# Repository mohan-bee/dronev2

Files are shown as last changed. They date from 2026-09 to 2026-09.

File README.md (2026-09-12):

# Drone V2

A compact, two-layer PCB microdrone with an interactive assembly viewer.

[Open the live 3D assembly studio](https://dronev2-cad.vercel.app)

- `pcb/` — tscircuit source, JLCPCB imports, mechanical dimensions, netlist tests and placement drawings.
- `cad/` — Three.js assembly viewer, generated PCB data and Vercel configuration.
- [ISSUES.md](ISSUES.md) — tooling blockers, mechanical assumptions and work required before routing/manufacture.

The two-layer specification supersedes the earlier four-layer proposal. Routing is deliberately disabled. No fabrication or flight release is implied.

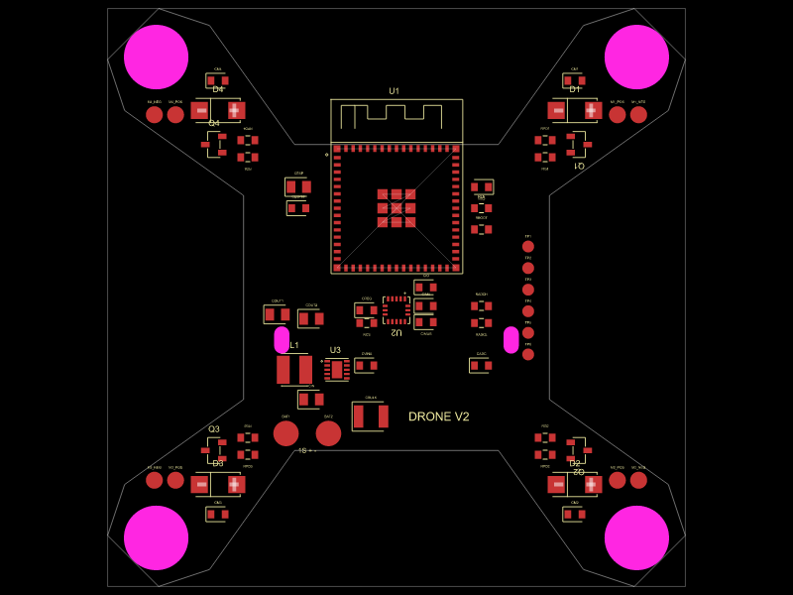
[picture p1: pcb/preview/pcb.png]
PCB placement


See [PCB instructions](pcb/README.md) for setup, validation, sourcing and pin mapping.

See [CAD instructions](cad/README.md) for the viewer, PCB sync, browser tests and deployment. The CAD PR is stacked on the PCB placement PR; merge the PCB first.

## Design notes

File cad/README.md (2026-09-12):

# Assembly studio

[Live viewer](https://dronev2-cad.vercel.app)

Interactive Three.js CAD-style viewer for the Drone V2 PCB. Orbit, inspect components, choose camera views, toggle parts, explode the assembly and export visible geometry as GLB. It does not edit PCB placement or control a flying drone.

```sh
cd cad
bun install --frozen-lockfile
bun run dev
bun run build
bunx playwright test
```

For tests, install Playwright Chromium with `bunx playwright install chromium` when a local Chrome installation is unavailable. Tests start the dev server automatically. `TEST_URL` can target an existing deployment.

## Updating the PCB

Build and validate `../pcb` first, then run `bun run sync-pcb`. The script refuses circuit JSON containing error records. It copies the source outline, holes, pads, component placements, drawing exports and vendor models into `public/pcb/`; `provenance.json` identifies the circuit JSON by SHA-256. Committed generated assets keep Vercel builds independent of the PCB toolchain.

## Model fidelity

PCB outline/holes/pads and electronic placements are compiled tscircuit data. Main components use JLCPCB-imported OBJ geometry, with approximate display materials because the importer did not provide material libraries. Passive parts use generic package envelopes. The four motors, propellers, battery, collars, guards, canopy, insulating pad and zip tie are provisional dimensional concepts. The canopy starts hidden so electronics can be inspected.

The page labels these limits. Export preserves visible parts and explosion state, converts millimetres to glTF metres and excludes the scene floor/grid and selection outline. Printed parts are not print-ready mechanical designs. No flight, mass or clearance validation is claimed.

## Deploy

Vercel project: `dronev2-cad`, GitHub root directory `cad`. Production is deployed from the repository root using its linked project, or through the Vercel GitHub integration after merge. No runtime environment variables are required. `.vercel/` and `.env*` are ignored.

## Verified result

Production smoke tests passed on the live URL: desktop model loading, component inspection, views, exploded state, selection/visibility consistency, GLB download, mobile layout and parts drawer. The rendered PCB provenance hash matches the compiled source.

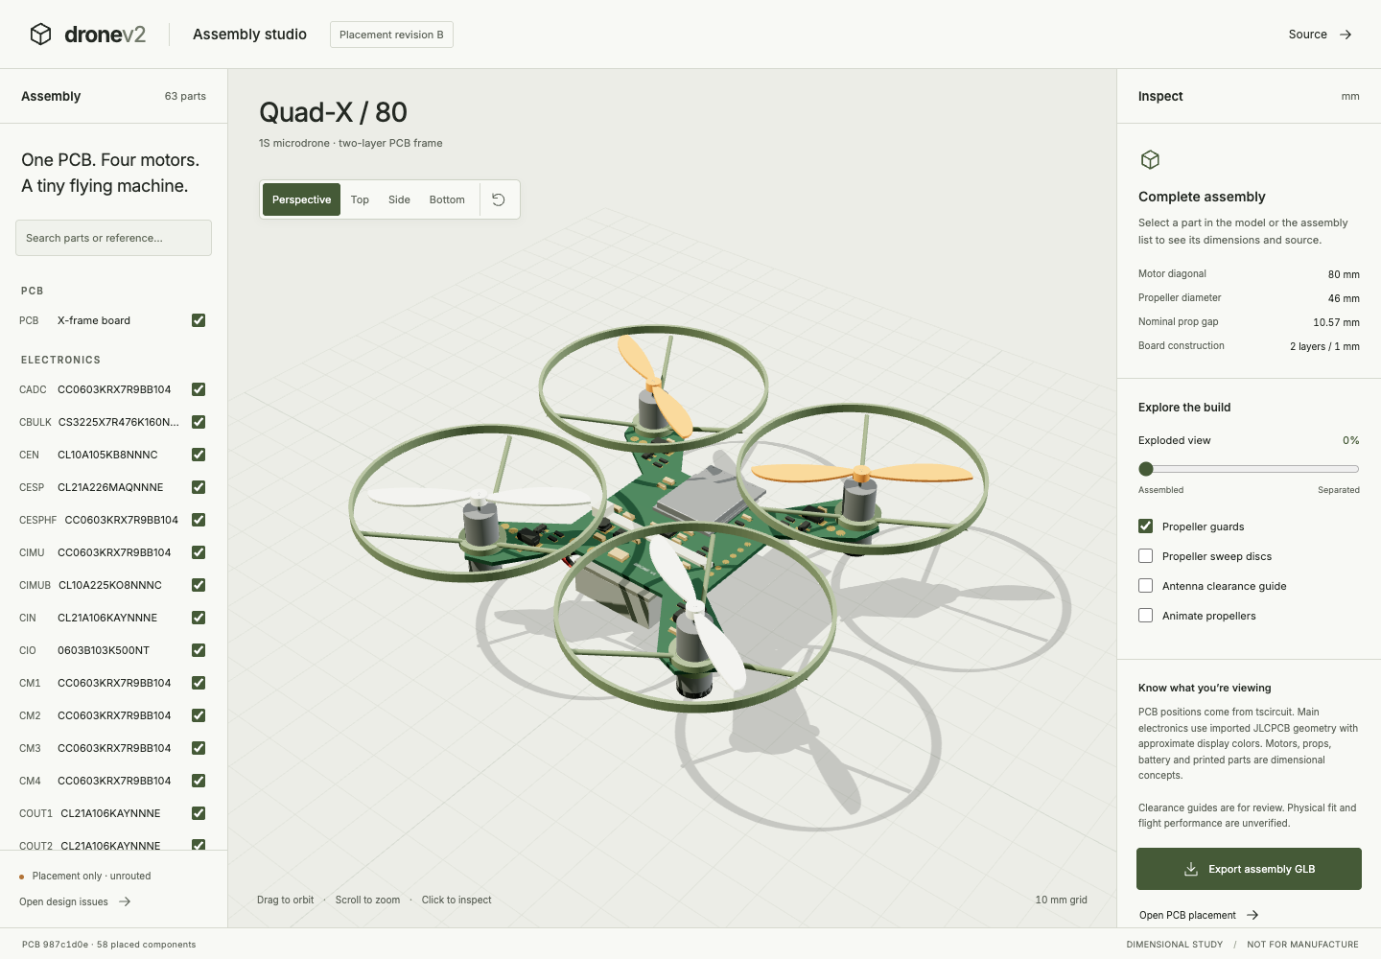
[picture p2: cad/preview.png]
Assembly studio


Revision B replaces the printed battery saddle with a 1 mm insulating pad and a 2.5 mm zip tie through two actual rounded PCB slots. The top run has a checked component-free lane. Motor collars are labeled as unselected mount placeholders; rubber supplier dimensions remain unresolved in ISSUES.md.

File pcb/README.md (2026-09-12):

# Compact PCB placement

A 68 × 68 mm X-shaped PCB frame with 58 top-side placed components/pads, 80 mm opposite-motor spacing, four 7.6 mm collar openings, and an ESP32-S3 antenna overhanging the nose. The central body is 36 mm wide; nominal neighboring 46 mm prop discs have 10.57 mm clearance. PCB thickness is 1.0 mm, two layers, FR-4. The fabrication target is 1 oz copper and ENIG, to be specified at order time.

## Run

Requires Bun. Dependencies are locked.

```sh
cd pcb
bun install --frozen-lockfile
bun run check
bun run build -- --routing-disabled --pcb-png --svgs
bun test
bun run typecheck
bun run dev
```

`index.circuit.tsx` is the source. `geometry.json` owns the outline and motor locations; `keepouts.json` records unenforced copper and mechanical requirements. The CAD viewer consumes the compiled output, not a second hand-placed board.

## Placement decisions

- U1 at (0, 10.5): every solder pad stays over the PCB; only the antenna body overhangs. Keep antenna space clear in the final assembled product.
- U2 at (0, -1.5), rotated 180°: near the center with local VDD/VDDIO/REGOUT capacitors. Configure firmware sensor axes from the actual package orientation.
- U3 and L1 form a compact cluster at the rear-left battery input. Input/output bypassing stays local; route these switching loops manually first. PS/SYNC is tied to VBAT for forced PWM; FB returns to V3V3.
- One Q/D/RG/RPD/CM group on each arm. Motor solder pads and flyback diodes stay close to the drain; GPIO gate traces travel inward. CM footprints are across motor terminals, not VBAT–GND. Also fit suppression at actual motor terminals if noise tests require it.
- Programming pads along the right edge. TP1 GND, TP2 **3V3_TEST**, TP3 controller TX, TP4 controller RX, TP5 EN, TP6 BOOT. TP2 is a measurement point, not an invitation to parallel an external supply with the regulator. Use a 3.3 V logic programmer.
- BAT1 is positive, BAT2 negative. Use a polarity-verified battery pigtail; no unverified connector footprint is assumed.
- Holes H5/H6 reserve potential printed-part attachment locations; no hardware should press beneath the IMU.

## Pin assignment

| Function | GPIO | Module pad |
|---|---:|---:|
| SPI clock | 12 | 16 |
| SPI MOSI | 11 | 15 |
| SPI MISO | 13 | 17 |
| IMU CS | 8 | 12 |
| IMU interrupt | 14 | 18 |
| Motor M1 | 39 | 35 |
| Motor M2 | 40 | 36 |
| Motor M3 | 41 | 37 |
| Motor M4 | 42 | 38 |
| Battery ADC | 1 | 5 |
| UART TX / RX | 43 / 44 | 39 / 40 |
| BOOT / EN | 0 / — | 4 / 45 |

M1 is front-right, M2 rear-right, M3 rear-left, M4 front-left; +Y is forward. CW/CCW in CAD is a proposed alternating arrangement, not a verified ESP-FC mixer order. Firmware, rotation and sensor-axis configuration remain a separate task.

## JLCPCB sourcing

Exact EasyEDA footprints plus local OBJ/STEP models were imported using:

```sh
bunx tsci import C2913206 --jlcpcb --download --use-exact-footprint
```

Repeated for C97633, C15516, C20917, C8678 and C2041714. Reimporting may overwrite generated files; the board overrides the unreadable imported AO3400A schematic symbol with a pin box and retains its footprint/model. Importer-generated pin aliases such as `pin7` on TPS63031 are wired by verified numeric pad mapping.

See [bom.csv](bom.csv) for the selected parts. Generic passive footprints carry explicit JLCPCB candidate codes; they are not all individually imported vendor footprints. Stock and pricing are not reserved. Capacitor effective capacitance and inductor saturation require qualification under actual operating conditions.

## Validation scope

See [reports/validation.md](reports/validation.md). Checks cover connectivity and placement; there are no routed copper traces. The independent netlist assertions cover regulator pin mapping, sensor reserved pins, SPI mapping and all four low-side motor circuits. Nothing here validates thrust, thermal margins, RF performance or flight firmware.

## Manufacturer references

- [ESP32-S3-MINI-1 datasheet](https://documentation.espressif.com/esp32-s3-mini-1_mini-1u_datasheet_en.html)
- [ICM-20602 datasheet](https://invensense.tdk.com/wp-content/uploads/2020/11/DS-000176-ICM-20602-v1.1.pdf)
- [TPS63030/TPS63031 datasheet](https://www.ti.com/lit/ds/symlink/tps63030.pdf)
- [AO3400A datasheet](https://www.aosmd.com/sites/default/files/res/datasheets/AO3400A.pdf)
- [Selected Bourns inductor listing](https://jlcpcb.com/partdetail/BOURNS-SRN30151R5Y/C2041714)
- [ESP-FC firmware](https://github.com/rtlopez/esp-fc)

The user's two supplied specifications are preserved under `docs/`.

Battery retention uses one 2.5 mm zip tie through H5/H6 (1.8 × 3.2 mm rounded slots) at x=±13.5, y=-5 mm, with a thin insulating pad. The top strap lane is kept clear of components. No printed battery saddle is required. Fit and slip testing remain necessary.

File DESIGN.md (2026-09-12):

# Assembly studio

Mode: Operate. A light model-making bench: warm off-white canvas, ink typography, olive active controls, orange selection. The assembly owns most of the viewport. Parts hierarchy at left; dimensional inspection at right. Dense data uses tabular numerals. Controls stay ordinary buttons, checkboxes and sliders.

The user delegated the stack and visual direction and requested a direct build. Considered systems: engineering drawing, parts catalogue, camera workbench, flight checklist, model-making bench, service manual, fabrication traveler. Selected model-making bench. Map legend contributes explicit symbols; oscilloscope contributes measured scale; folding sheet contributes reversible explosion. Game sprites, typographic storms and scroller queues undermine dimensional clarity and are declined.

Tokens: canvas #ecede7; paper #f8f9f5; ink #242923; secondary #60665c; rule #d6d9cf; active #455a37; highlight #c66935. Inter Variable, 13px body baseline; 28px scene heading (weight 450), 15px header title (weight 500), 23px brand. Controls generally use 11px, metadata 9–10px. Spacing is contextual rather than a strict 4px grid. Corners are 3px on rows/view buttons, 4px on search/export, and 5px on the toolbar. Real model geometry with ground shadow, no decorative cards. At 820px and below, mobile puts the canvas (64dvh, minimum 430px) before a two-column inspector in document flow. Only the assembly list becomes a 260px overlay, toggled by Parts.

## Layout and interaction details

Desktop has a 72px header, a 238px / flexible canvas / 276px workspace, and a 33px footer. The workspace has a 620px minimum height; side panels scroll independently. At 1600px and above side columns become 265px and 300px. At 1100px and below they become 205px and 240px, panel padding falls from 22px to 17px, and revision/grid captions hide. Mobile uses a 60px header and a 24px scene heading.

Selection uses a pale olive list row (#e0e7d7, text #304424) and an orange bounding box in the model. Focus-visible outlines are olive, 2px with 4px offset. The toolbar has a faint shadow (0 3px 8px #24292308); the mobile parts overlay uses 8px 10px 30px #24292325. Export hover darkens to #34462a; pending buttons have half opacity and a wait cursor.

Camera presets switch directly; reset restores perspective and collapses explosion. Slider changes directly separate model groups and refit the camera. Orbit uses damping. Propeller animation is opt-in and disabled when reduced motion is requested at load. Selection, camera changes and export status are announced in a polite live region. Export contains the visible assembly.

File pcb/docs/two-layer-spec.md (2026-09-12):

**Yes—we can build this as a two-layer PCB, with the PCB itself forming the drone’s body and all components assembled on top.** Espressif explicitly allows two-layer ESP32-S3 designs, provided the bottom layer remains mostly an uninterrupted ground reference rather than becoming another busy signal-routing layer. ([docs.espressif.com][1])

For your drone, I would keep the selected **ESP32-S3-MINI-1-N8, ICM-20602, TPS63031, and four AO3400A motor switches**.

**Two layers do not inherently create control lag.** The concern is electrical noise and voltage dips from the motors—not “buffering” caused by the layer count. Motor noise can disturb sensors and even reset a controller, so the power layout deserves particular attention. ([Pololu][2])

# 1. PCB specification I would start with

These are **proposed design targets**, not a flight-tested mechanical design.

| Item | Proposed specification |
| --- | --- |
| Board construction  | **Two-layer FR-4** |
| Board thickness | **1.0 mm initially**, then verify stiffness |
| Copper | **1 oz on both sides** |
| Surface finish | **ENIG preferred** |
| Component assembly  | **Top side only** |
| Shape | **X-shaped PCB that also serves as the frame** |
| Motor spacing | **80 mm between opposite motor centres** |
| Propellers | **46 mm** |
| Motor mounting | Printed collars attached to the PCB arms |
| Battery mounting | Under the centre, with electrical insulation |
| Complete drone mass | Continue targeting **30–35 g**, subject to measured thrust |

JLCPCB lists two-layer FR-4, 1.0 mm thickness, 1 oz copper, and ENIG among its manufacturing options. These choices do not establish the final assembly price or component inventory. ([JLCPCB][3])

At an 80 mm motor diagonal, adjacent motor centres are approximately **56.6 mm apart**. With 46 mm propellers, the nominal gap between adjacent propeller discs is approximately **10.6 mm**.

**Do not make the arms extremely thin just to reduce weight.** My preference is to begin with fairly broad, rounded arm roots, then remove material only after checking mass and flex.

# 2. Decide what belongs on each copper layer

| Top copper | Bottom copper |
| --- | --- |
| All component footprints | Mostly connected GND copper |
| Battery-positive distribution | Motor-current return paths through broad ground areas |
| Short motor-switching connections | Ground connections for controller and power circuitry |
| Regulated 3.3 V distribution | Only a few short signal crossings where necessary |
| SPI, motor-control, and programming signals | Required antenna and sensor footprint keepouts |

The manufacturer-backed principle is **top-side components and signals, with minimal bottom routing**. ([docs.espressif.com][1])

For this design, I would use **one common GND net**, while arranging the components and power branches so motor current does not have to squeeze through the controller/sensor area. Do not create separate, floating “motor ground” and “sensor ground” islands.

There are two important exceptions to a broad ground pour: the **antenna clearance area** and the **local keepout under the IMU package**. The latter follows TDK’s sensor-layout guidance; it is a small footprint-level clearance, not a long slot dividing the whole board. ([Mouser Electronics][4])

# 3. Place components before routing anything

### ESP module: front edge, antenna facing outward

Position the module so its antenna end extends beyond the supporting PCB edge where practical. Keep the battery, motor wires, and printed attachments away from that area. Espressif recommends antenna clearance in the finished product and testing the final assembly’s communication performance. ([Espressif Systems][1])

**Do not remove ground beneath the entire module.** Apply the antenna keepout specifically, while following the recommended land pattern for the rest of the module.

### IMU: near the centre, in a mechanically quiet location

I would put the ICM-20602 near the centre of the drone, but allow a slight offset to avoid a mounting point, heavily flexing area, or hot component.

Keep it away from the regulator’s inductor, motor-current paths, mounting screws, and pressure from the battery holder. TDK specifically warns about mechanical stress, heat sources, vibration, and connectors or test fixtures directly beneath an IMU. ([Mouser Electronics][4])

### Regulator: beside the battery input

Place the TPS63031, its inductor, and its input/output capacitors together as a compact group. Do not scatter them around spare spaces on the PCB. TI’s layout guidance calls for short, wide power connections and closely placed capacitors and inductor.

### Motor circuits: one group near each motor connection

My proposed arrangement is one MOSFET, diode, gate resistor, and gate pull-down near each motor’s solder pads. This keeps the switched motor-negative connection short, while the much lower-current gate-control trace travels along the arm.

### Programming pads: accessible along a side

Keep programming access away from the IMU and outside the battery-holder contact area. You should be able to connect a programmer without removing motors or pressing on the sensor.

# 4. Draw the schematic in five blocks

## A. Battery input and 3.3 V supply

Use this power arrangement:

```text
1S LiPo positive
    |
    +---- Motor 1 positive
    +---- Motor 2 positive
    +---- Motor 3 positive
    +---- Motor 4 positive
    |
    +---- TPS63031 ---- regulated 3.3 V
                           |
                           +---- ESP32-S3 module
                           +---- ICM-20602

Battery negative -------- common GND
```

**The motors connect to the battery rail—not the regulator’s 3.3 V output.**

For the TPS63031, start from TI’s **fixed-3.3 V application circuit**, not the adjustable TPS63030 circuit:

| Item | Reference-circuit value / connection |
| --- | --- |
| Inductor | **1.5 µH**, appropriately rated for peak current |
| Input capacitor | **10 µF** |
| Output capacitors | **2 × 10 µF** |
| VINA bypass capacitor | **100 nF** |
| FB pin | Connect to the 3.3 V output |
| EN | Defined high for normal always-on operation |
| PS/SYNC | High disables power-save mode; low enables it |

The capacitor values must remain adequate after voltage derating. Follow TI’s local power-ground/control-ground arrangement and exposed-pad requirements.

For the first prototype, I would provision **PS/SYNC high during flight** and reserve space for additional battery-rail bulk capacitance.

**Power-budget caution:** TPS63031 is specified for up to 500 mA in boost operation under its stated conditions; its “1-A switches” description is not a 1 A output guarantee. Espressif recommends a supply capable of at least 500 mA. This makes low-battery, radio-active testing essential before accepting this regulator for the finished drone. ([Texas Instruments][5])

## B. ESP32-S3 minimum circuit

For the module—not a bare ESP32-S3 chip—include:

| Connection | Implementation |
| --- | --- |
| 3V3 | Regulated 3.3 V |
| Local supply capacitors | **22 µF + 100 nF**, as shown in the module reference |
| EN | **10 kΩ pull-up to 3.3 V + 1 µF to GND** as the initial reset network |
| BOOT / GPIO0 | Accessible connection to GND for entering download mode |
| UART | TX, RX, and GND programming pads |
| Ground pads | Connect according to the module land pattern |

The module reference provides the supply and reset circuitry; the EN timing should still be checked with the actual regulator.

I would add an external **10 kΩ GPIO0 pull-up** and expose:

```text
GND   3V3_TEST   TX   RX   EN   BOOT
```

Use a **3.3 V-logic programmer**. Label `3V3_TEST` clearly: it should not encourage connecting an external supply in parallel with the onboard regulator.

## C. ICM-20602 circuit

Power **VDD and VDDIO from the regulated sensor supply**, not directly from the LiPo.

Use the manufacturer’s actual capacitor arrangement:

| ICM-20602 connection | Required external connection |
| --- | --- |
| VDD, pin 16 | **100 nF + 2.2 µF** to GND |
| VDDIO, pin 1 | **10 nF** to GND |
| REGOUT, pin 14 | **100 nF** to GND |
| FSYNC, pin 8 | GND when unused |
| Reserved pin 7 | Leave electrically unconnected |
| Reserved pins 9, 10, 11, 12, 15 | GND |
| GND, pin 13 | GND |

**REGOUT is not a general-purpose supply output.** Also, do not treat every reserved pin identically.

Use SPI: clock to `SCL/SPC`, MOSI to `SDA/SDI`, MISO from `SA0/SDO`, and a GPIO-controlled `CS`. I would add a **10 kΩ CS pull-up** and reserve an interrupt connection. Do not copy the datasheet’s I²C example with CS permanently tied high.

Place these capacitors immediately beside their corresponding pins. Keep SPI routes short, reasonably similar in length, and away from switching-power traces; respect the under-package copper/via keepout. ([Mouser Electronics][4])

## D. Four brushed-motor driver circuits

Repeat this circuit four times:

```text
VBAT -------------------- Motor positive
                              |
                            MOTOR
                              |
Motor negative ---------------+---- AO3400A DRAIN

AO3400A SOURCE -------------------- GND

ESP motor GPIO ---- 100 Ω --------- AO3400A GATE
                                      |
                                    100 kΩ
                                      |
                                  SOURCE / GND
```

Place the **SS34 diode across the motor connection**:

**Diode cathode → VBAT / motor positive.**
**Diode anode → motor negative / MOSFET drain.**

This low-side-switch and flyback-diode topology is also used in Espressif’s drone reference, although its exact transistor, diode, and resistor choices differ.

The 100 Ω and 100 kΩ values above are my proposed starting values. Put both close to the MOSFET. Verify the actual AO3400A footprint’s gate/source/drain mapping against its datasheet, rather than trusting an imported symbol.

For motor-noise suppression, provision a small ceramic capacitor across each motor’s terminals. Pololu recommends terminal capacitors and short, twisted motor leads; its general starting recommendation is 100 nF. Validate the chosen capacitor with your motor PWM and switching waveform. ([Pololu][2])

**A capacitor between VBAT and GND is not the same connection as a capacitor across the motor.**

## E. Battery-voltage measurement

My proposed measurement circuit is:

```text
VBAT ---- 100 kΩ ----+---- ADC input
                    |
                  100 kΩ
                    |
                   GND

ADC input ---- 100 nF ---- GND
```

The equal resistor divider gives:

$$
V_{\text{ADC}} = V_{\text{battery}}/2
$$

Therefore, a 4.2 V battery produces approximately **2.1 V at the ADC input**.

Calibrate the reported voltage against a multimeter. Battery warnings should use the measured pack voltage, not an assumed value from the resistor labels alone.

# 5. Use a firmware-compatible pin assignment

**Start with ESP-FC’s documented ESP32-S3 defaults** rather than inventing a completely different pinout.

| Function | ESP32-S3 GPIO |
| --- | ---: |
| IMU SPI clock | **12** |
| IMU MOSI | **11** |
| IMU MISO | **13** |
| IMU chip select | **8** |
| Motor output 1  | **39** |
| Motor output 2  | **40** |
| Motor output 3  | **41** |
| Motor output 4  | **42** |
| Battery ADC | **1** |
| UART TX | **43** |
| UART RX | **44** |

These assignments come from ESP-FC’s wiring documentation. Confirm them against the firmware revision you actually build. ([GitHub][6])

**GPIO numbers are not module pad numbers.** Your schematic symbol must map them correctly.

GPIO39–42 also have JTAG functions, so do not connect an external JTAG interface to them while they are motor controls. Avoid assigning motor outputs to the boot-strapping GPIOs **0, 3, 45, and 46**.

ESP-FC lists support for **ESP32-S3, ICM20602, and BRUSHED outputs**. Select the brushed output protocol and verify the physical motor order against the mixer before attaching propellers. ([GitHub][7])

# 6. Routing rules for this two-layer version

### Starting trace widths

These are **initial layout allowances—not guaranteed current ratings**.

| Connection | Starting width / approach |
| --- | --- |
| SPI and ordinary signals | **0.20–0.25 mm** |
| Local fine-pitch escape | **0.15 mm where necessary** |
| Main regulated 3.3 V feed | **0.8–1.0 mm** |
| Individual motor-current path | Begin around **1.0–1.5 mm**, wider where practical |
| Shared battery-positive distribution | Broad copper region; initially allow **2.5–3 mm or more** |
| Ground return | Broad connected copper, without narrow bottlenecks |
| Ordinary vias | **0.30 mm drill / 0.60 mm pad** |
| General trace clearance | **0.20 mm**, with reviewed local exceptions |

These ordinary trace/via choices are comfortably above several of JLCPCB’s published minimum capabilities. Fine-pitch footprints and power paths still need individual review. ([JLCPCB][3])

**Size motor copper using measured loaded current and startup current.** The shared battery feed carries all four motors plus the electronics; a trace that is adequate for one motor is not automatically adequate for the common feed.

### My routing order

**First, finish the regulator’s local placement and connections.** Then route the battery distribution and motor circuits, keeping space reserved for the IMU-to-ESP connection. Route SPI next, followed by programming, battery measurement, and remaining signals.

For this project, I would lock the power and sensor routes before autorouting any remaining low-current connections.

### Ground and switching details

Keep the MOSFET drain copper **compact**, rather than turning each switched motor-negative net into a large copper pour. Give the source-to-ground connection a broad path, and use multiple suitably sized vias wherever substantial motor current changes layers.

Do not allow a bottom-side signal trace to cut across an entire arm or divide the central ground region. A bottom trace can be short yet still create a bad ground bottleneck.

For the TPS63031, reproduce the manufacturer’s local layout closely instead of relying on a generic “connect everything to the ground pour” approach.

# 7. Mechanical and 3D checks

For this version, I would design **motor collars, propeller guards, an insulated battery saddle, and a very small protective canopy**—not a second structural frame.

**Motor collars:** print a fit-test piece using the actual motors. The collar should retain the motor without crushing its casing or allowing the thrust direction to tilt.

**Propeller clearance:** check the full swept disc in CAD, including blade height, guard flex, component height, and motor-wire position. A top-view circle check alone is insufficient.

**Battery holder:** use a proper insulating barrier between the battery and PCB. Keep sharp board edges, solder joints, and protruding hardware away from the pouch. The holder should not press directly beneath the IMU.

**Frame stiffness:** start with 1.0 mm FR-4, but do not assume it is automatically stiff enough. Test arm flex and vibration before committing to a larger batch.

Espressif supplies the module’s recommended footprint and STEP-model resources in its datasheet, which are useful for the enclosure and clearance model.

# 8. Checks before ordering and before flight

| Stage | What I would require |
| --- | --- |
| **Before PCB order** | Electrical and layout checks; verified footprints and pin 1; correct diode polarity; antenna clearance; no ground bottlenecks; mechanical clearance model; finalized inductor and capacitor part numbers |
| **First power-up** | Current-limited bench supply, props removed, checked polarity and 3.3 V rail, no unexpected heating |
| **Motor testing** | Props-off motor order and direction; then separate guarded loaded-propulsion testing for current, thrust, and heating |
| **Radio and sensor testing** | Monitor 3.3 V and IMU supply while radio and motors operate; inspect sensor data; verify reset behaviour and loss-of-link failsafe |
| **Before free flight** | Correct IMU axes, calibrated battery reading, verified arming behaviour, measured all-up mass, sufficient measured thrust |

ESP-FC specifically instructs users to test motor configuration with propellers removed. ([GitHub][7])

**My recommendation: proceed with two layers for this version.** Keep the design simple, preserve the ground return paths, and give the regulator and IMU placement priority over making the board look symmetrical. The schematic, selected power components, and finished routing still need review before this becomes a manufacturing-ready drone PCB.

[1]: https://docs.espressif.com/projects/esp-hardware-design-guidelines/en/latest/esp32s3/pcb-layout-design.html "PCB Layout Design - ESP32-S3 - — ESP Hardware Design Guidelines latest documentation"
[2]: https://www.pololu.com/docs/0J15/9 "Pololu - 9. Dealing with Motor Noise"
[3]: https://jlcpcb.com/capabilities/Capabilities?utm_source=chatgpt.com "PCB Manufacturing & Assembly Capabilities - JLCPCB"
[4]: https://www.mouser.com/pdfDocs/tdk-invensense-an-000393.pdf "AN-000393"
[5]: https://www.ti.com/lit/ds/symlink/tps63030.pdf "TPS6303x High Efficiency Single Inductor	 Buck-Boost Converter With 1-A Switches datasheet (Rev. D)"
[6]: https://github.com/rtlopez/esp-fc/blob/master/docs/wiring.md "esp-fc/docs/wiring.md at master · rtlopez/esp-fc · GitHub"
[7]: https://github.com/rtlopez/esp-fc "GitHub - rtlopez/esp-fc: Flight controller software for hobbyist - build your own flight controller. · GitHub"

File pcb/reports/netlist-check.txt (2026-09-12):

Detected entrypoint: 'index.circuit.tsx'
Each child in a list should have a unique "key" prop.

Check the render method of `board`. It was passed a child from Drone. See https://react.dev/link/warning-keys for more information.
trace: `key` is not a prop. Trying to access it will result in `undefined` being returned. If you need to access the same value within the child component, you should pass it as a different prop. (https://react.dev/link/special-props)
Errors: 0
Warnings: 0

Readable Netlist:
COMPONENTS:
 - U1: ESP32-S3-MINI-1-N8
 - U2: ICM-20602
 - U3: TPS63031DSKR
 - L1: L1, source_component
 - CIN: 10uF capacitor
 - COUT1: 10uF capacitor
 - COUT2: 10uF capacitor
 - CVINA: 100nF capacitor
 - CBULK: 47uF capacitor
 - CESP: 22uF capacitor
 - CESPHF: 100nF capacitor
 - CEN: 1uF capacitor
 - CIMU: 100nF capacitor
 - CIMUB: 2.2uF capacitor
 - CIO: 10nF capacitor
 - CREG: 100nF capacitor
 - CADC: 100nF capacitor
 - REN: 10kΩ resistor
 - RBOOT: 10kΩ resistor
 - RCS: 10kΩ resistor
 - RADCH: 100kΩ resistor
 - RADCL: 100kΩ resistor
 - TP1: TP1, source_component
 - TP2: TP2, source_component
 - TP3: TP3, source_component
 - TP4: TP4, source_component
 - TP5: TP5, source_component
 - TP6: TP6, source_component
 - BAT1: BAT1, source_component
 - BAT2: BAT2, source_component
 - Q1: AO3400A
 - D1: D1, source_component
 - RG1: 100Ω resistor
 - RPD1: 100kΩ resistor
 - CM1: 100nF capacitor
 - M1_POS: M1_POS, source_component
 - M1_NEG: M1_NEG, source_component
 - Q2: AO3400A
 - D2: D2, source_component
 - RG2: 100Ω resistor
 - RPD2: 100kΩ resistor
 - CM2: 100nF capacitor
 - M2_POS: M2_POS, source_component
 - M2_NEG: M2_NEG, source_component
 - Q3: AO3400A
 - D3: D3, source_component
 - RG3: 100Ω resistor
 - RPD3: 100kΩ resistor
 - CM3: 100nF capacitor
 - M3_POS: M3_POS, source_component
 - M3_NEG: M3_NEG, source_component
 - Q4: AO3400A
 - D4: D4, source_component
 - RG4: 100Ω resistor
 - RPD4: 100kΩ resistor
 - CM4: 100nF capacitor
 - M4_POS: M4_POS, source_component
 - M4_NEG: M4_NEG, source_component

NET: VBAT_ADC
  - U1 IO1
  - RADCL pin1
  - RADCH pin2
  - CADC pin1 (+)

NET: IMU_SCK
  - U2 pin2
  - U1 IO12

NET: IMU_MOSI
  - U2 pin3
  - U1 IO11

NET: IMU_MISO
  - U2 pin4
  - U1 IO13

NET: IMU_CS
  - U2 CS
  - U1 IO8
  - RCS pin2

NET: IMU_INT
  - U2 INT
  - U1 IO14

NET: REGOUT
  - U2 REGOUT
  - CREG pin1 (+)

NET: L1
  - L1 pin1 (+)
  - U3 L1

NET: L2
  - L1 pin2 (-)
  - U3 L2

NET: V3V3
  - TP2 pin1
  - U3 FB
  - U3 VOUT
  - U2 VDD
  - U2 VDDIO
  - U1 3V3
  - RCS pin1
  - RBOOT pin1
  - REN pin1
  - CIO pin1 (+)
  - CIMUB pin1 (+)
  - CIMU pin1 (+)
  - CESPHF pin1 (+)
  - CESP pin1 (+)
  - COUT2 pin1 (+)
  - COUT1 pin1 (+)

NET: UART_TX
  - TP3 pin1
  - U1 TXD0

NET: UART_RX
  - TP4 pin1
  - U1 RXD0

NET: EN
  - TP5 pin1
  - U1 EN
  - REN pin2
  - CEN pin1 (+)

NET: BOOT
  - TP6 pin1
  - U1 IO0
  - RBOOT pin2

NET: M1_PWM
  - RG1 pin1
  - U1 IO39

NET: M1_GATE
  - RPD1 pin1
  - RG1 pin2
  - Q1 G

NET: M1_NEG
  - M1_NEG pin1
  - CM1 pin2 (-)
  - D1 anode (+)
  - Q1 D

NET: M2_PWM
  - RG2 pin1
  - U1 IO40

NET: M2_GATE
  - RPD2 pin1
  - RG2 pin2
  - Q2 G

NET: M2_NEG
  - M2_NEG pin1
  - CM2 pin2 (-)
  - D2 anode (+)
  - Q2 D

NET: M3_PWM
  - RG3 pin1
  - U1 IO41

NET: M3_GATE
  - RPD3 pin1
  - RG3 pin2
  - Q3 G

NET: M3_NEG
  - M3_NEG pin1
  - CM3 pin2 (-)
  - D3 anode (+)
  - Q3 D

NET: M4_PWM
  - RG4 pin1
  - U1 IO42

NET: M4_GATE
  - RPD4 pin1
  - RG4 pin2
  - Q4 G

NET: GND
  - RPD4 pin2
  - Q4 S
  - RPD3 pin2
  - Q3 S
  - RPD2 pin2
  - Q2 S
  - RPD1 pin2
  - Q1 S
  - BAT2 pin1
  - TP1 pin1
  - U3 EP
  - U3 GND
  - U3 PGND
  - U2 RESV6
  - U2 GND
  - U2 RESV5
  - U2 RESV4
  - U2 RESV3
  - U2 RESV2
  - U2 FSYNC
  - U1 GND20
  - U1 pin61_internal_1
  - U1 pin61_internal_2
  - U1 pin61_internal_3
  - U1 pin61_internal_4
  - U1 pin61_internal_5
  - U1 pin61_internal_6
  - U1 pin61_internal_7
  - U1 pin61_internal_8
  - U1 pin61_internal_9
  - U1 pin61_internal_10
  - U1 pin61_internal_11
  - U1 pin61_internal_12
  - U1 GND19
  - U1 GND18
  - U1 GND17
  - U1 GND16
  - U1 GND15
  - U1 GND14
  - U1 GND13
  - U1 GND12
  - U1 GND11
  - U1 GND10
  - U1 GND9
  - U1 GND8
  - U1 GND7
  - U1 GND6
  - U1 GND5
  - U1 GND4
  - U1 GND3
  - U1 GND2
  - U1 GND1
  - RADCL pin2
  - CADC pin2 (-)
  - CREG pin2 (-)
  - CIO pin2 (-)
  - CIMUB pin2 (-)
  - CIMU pin2 (-)
  - CEN pin2 (-)
  - CESPHF pin2 (-)
  - CESP pin2 (-)
  - CBULK pin2 (-)
  - CVINA pin2 (-)
  - COUT2 pin2 (-)
  - COUT1 pin2 (-)
  - CIN pin2 (-)

NET: VBAT
  - M4_POS pin1
  - CM4 pin1 (+)
  - D4 cathode (-)
  - M3_POS pin1
  - CM3 pin1 (+)
  - D3 cathode (-)
  - M2_POS pin1
  - CM2 pin1 (+)
  - D2 cathode (-)
  - M1_POS pin1
  - CM1 pin1 (+)
  - D1 cathode (-)
  - BAT1 pin1
  - U3 VINA
  - U3 pin7
  - U3 EN
  - U3 VIN
  - RADCH pin1
  - CBULK pin1 (+)
  - CVINA pin1 (+)
  - CIN pin1 (+)

NET: M4_NEG
  - M4_NEG pin1
  - CM4 pin2 (-)
  - D4 anode (+)
  - Q4 D

COMPONENT_PINS:
U1 (ESP32-S3-MINI-1-N8)
- pin61_internal_1(pin61, 61): NETS(GND)
- pin61_internal_2(pin61, 61): NETS(GND)
- pin61_internal_3(pin61, 61): NETS(GND)
- pin61_internal_4(pin61, 61): NETS(GND)
- pin61_internal_5(pin61, 61): NETS(GND)
- pin61_internal_6(pin61, 61): NETS(GND)
- pin61_internal_7(pin61, 61): NETS(GND)
- pin61_internal_8(pin61, 61): NETS(GND)
- pin61_internal_9(pin61, 61): NETS(GND)
- pin61_internal_10(pin61, 61): NETS(GND)
- pin61_internal_11(pin61, 61): NETS(GND)
- pin61_internal_12(pin61, 61): NETS(GND)
- pin1(GND1): NETS(GND)
- pin2(GND2): NETS(GND)
- pin3(3V3): NETS(V3V3)
- pin4(IO0): NETS(BOOT)
- pin5(IO1): NETS(VBAT_ADC)
- pin6(IO2): NOT_CONNECTED
- pin7(IO3): NOT_CONNECTED
- pin8(IO4): NOT_CONNECTED
- pin9(IO5): NOT_CONNECTED
- pin10(IO6): NOT_CONNECTED
- pin11(IO7): NOT_CONNECTED
- pin12(IO8): NETS(IMU_CS)
- pin13(IO9): NOT_CONNECTED
- pin14(IO10): NOT_CONNECTED
- pin15(IO11): NETS(IMU_MOSI)
- pin16(IO12): NETS(IMU_SCK)
- pin17(IO13): NETS(IMU_MISO)
- pin18(IO14): NETS(IMU_INT)
- pin19(IO15): NOT_CONNECTED
- pin20(IO16): NOT_CONNECTED
- pin21(IO17): NOT_CONNECTED
- pin22(IO18): NOT_CONNECTED
- pin23(IO19): NOT_CONNECTED
- pin24(IO20): NOT_CONNECTED
- pin25(IO21): NOT_CONNECTED
- pin26(IO26): NOT_CONNECTED
- pin27(IO47): NOT_CONNECTED
- pin28(IO33): NOT_CONNECTED
- pin29(IO34): NOT_CONNECTED
- pin30(IO48): NOT_CONNECTED
- pin31(IO35): NOT_CONNECTED
- pin32(IO36): NOT_CONNECTED
- pin33(IO37): NOT_CONNECTED
- pin34(IO38): NOT_CONNECTED
- pin35(IO39): NETS(M1_PWM)
- pin36(IO40): NETS(M2_PWM)
- pin37(IO41): NETS(M3_PWM)
- pin38(IO42): NETS(M4_PWM)
- pin39(TXD0): NETS(UART_TX)
- pin40(RXD0): NETS(UART_RX)
- pin41(IO45): NOT_CONNECTED
- pin42(GND3): NETS(GND)
- pin43(GND4): NETS(GND)
- pin44(IO46): NOT_CONNECTED
- pin45(EN): NETS(EN)
- pin46(GND5): NETS(GND)
- pin47(GND6): NETS(GND)
- pin48(GND7): NETS(GND)
- pin49(GND8): NETS(GND)
- pin50(GND9): NETS(GND)
- pin51(GND10): NETS(GND)
- pin52(GND11): NETS(GND)
- pin53(GND12): NETS(GND)
- pin54(GND13): NETS(GND)
- pin55(GND14): NETS(GND)
- pin56(GND15): NETS(GND)
- pin57(GND16): NETS(GND)
- pin58(GND17): NETS(GND)
- pin59(GND18): NETS(GND)
- pin60(GND19): NETS(GND)
- pin61(GND20): NETS(GND)

U2 (ICM-20602)
- pin1(VDDIO): NETS(V3V3)
- pin2: NETS(IMU_SCK)
- pin3: NETS(IMU_MOSI)
- pin4: NETS(IMU_MISO)
- pin5(CS): NETS(IMU_CS)
- pin6(INT): NETS(IMU_INT)
- pin7(RESV1): NOT_CONNECTED
- pin8(FSYNC): NETS(GND)
- pin9(RESV2): NETS(GND)
- pin10(RESV3): NETS(GND)
- pin11(RESV4): NETS(GND)
- pin12(RESV5): NETS(GND)
- pin13(GND): NETS(GND)
- pin14(REGOUT): NETS(REGOUT)
- pin15(RESV6): NETS(GND)
- pin16(VDD): NETS(V3V3)

U3 (TPS63031DSKR)
- pin1(VOUT): NETS(V3V3)
- pin2(L2): NETS(L2)
- pin3(PGND): NETS(GND)
- pin4(L1): NETS(L1)
- pin5(VIN): NETS(VBAT)
- pin6(EN): NETS(VBAT)
- pin7: NETS(VBAT)
- pin8(VINA): NETS(VBAT)
- pin9(GND): NETS(GND)
- pin10(FB): NETS(V3V3)
- pin11(EP): NETS(GND)

L1 (SRN3015-1R5Y)
- pin1(anode, pos, left): NETS(L1)
- pin2(cathode, neg, right): NETS(L2)

CIN (10uF undefined)
- pin1(anode, pos, left): NETS(VBAT)
- pin2(cathode, neg, right): NETS(GND)

COUT1 (10uF undefined)
- pin1(anode, pos, left): NETS(V3V3)
- pin2(cathode, neg, right): NETS(GND)

COUT2 (10uF undefined)
- pin1(anode, pos, left): NETS(V3V3)
- pin2(cathode, neg, right): NETS(GND)

CVINA (100nF undefined)
- pin1(anode, pos, left): NETS(VBAT)
- pin2(cathode, neg, right): NETS(GND)

CBULK (47uF undefined)
- pin1(anode, pos, left): NETS(VBAT)
- pin2(cathode, neg, right): NETS(GND)

CESP (22uF undefined)
- pin1(anode, pos, left): NETS(V3V3)
- pin2(cathode, neg, right): NETS(GND)

CESPHF (100nF undefined)
- pin1(anode, pos, left): NETS(V3V3)
- pin2(cathode, neg, right): NETS(GND)

CEN (1uF undefined)
- pin1(anode, pos, left): NETS(EN)
- pin2(cathode, neg, right): NETS(GND)

CIMU (100nF undefined)
- pin1(anode, pos, left): NETS(V3V3)
- pin2(cathode, neg, right): NETS(GND)

CIMUB (2.2uF undefined)
- pin1(anode, pos, left): NETS(V3V3)
- pin2(cathode, neg, right): NETS(GND)

CIO (10nF undefined)
- pin1(anode, pos, left): NETS(V3V3)
- pin2(cathode, neg, right): NETS(GND)

CREG (100nF undefined)
- pin1(anode, pos, left): NETS(REGOUT)
- pin2(cathode, neg, right): NETS(GND)

CADC (100nF undefined)
- pin1(anode, pos, left): NETS(VBAT_ADC)
- pin2(cathode, neg, right): NETS(GND)

REN (10kΩ undefined)
- pin1(anode, pos, left): NETS(V3V3)
- pin2(cathode, neg, right): NETS(EN)

RBOOT (10kΩ undefined)
- pin1(anode, pos, left): NETS(V3V3)
- pin2(cathode, neg, right): NETS(BOOT)

RCS (10kΩ undefined)
- pin1(anode, pos, left): NETS(V3V3)
- pin2(cathode, neg, right): NETS(IMU_CS)

RADCH (100kΩ undefined)
- pin1(anode, pos, left): NETS(VBAT)
- pin2(cathode, neg, right): NETS(VBAT_ADC)

RADCL (100kΩ undefined)
- pin1(anode, pos, left): NETS(VBAT_ADC)
- pin2(cathode, neg, right): NETS(GND)

TP1
- pin1: NETS(GND)

TP2
- pin1: NETS(V3V3)

TP3
- pin1: NETS(UART_TX)

TP4
- pin1: NETS(UART_RX)

TP5
- pin1: NETS(EN)

TP6
- pin1: NETS(BOOT)

BAT1
- pin1: NETS(VBAT)

BAT2
- pin1: NETS(GND)

Q1 (AO3400A)
- pin1(G): NETS(M1_GATE)
- pin2(S): NETS(GND)
- pin3(D): NETS(M1_NEG)

D1 (SS34)
- pin1(cathode, neg): NETS(VBAT)
- pin2(anode, pos): NETS(M1_NEG)

RG1 (100Ω undefined)
- pin1(anode, pos, left): NETS(M1_PWM)
- pin2(cathode, neg, right): NETS(M1_GATE)

RPD1 (100kΩ undefined)
- pin1(anode, pos, left): NETS(M1_GATE)
- pin2(cathode, neg, right): NETS(GND)

CM1 (100nF undefined)
- pin1(anode, pos, left): NETS(VBAT)
- pin2(cathode, neg, right): NETS(M1_NEG)

M1_POS
- pin1: NETS(VBAT)

M1_NEG
- pin1: NETS(M1_NEG)

Q2 (AO3400A)
- pin1(G): NETS(M2_GATE)
- pin2(S): NETS(GND)
- pin3(D): NETS(M2_NEG)

D2 (SS34)
- pin1(cathode, neg): NETS(VBAT)
- pin2(anode, pos): NETS(M2_NEG)

RG2 (100Ω undefined)
- pin1(anode, pos, left): NETS(M2_PWM)
- pin2(cathode, neg, right): NETS(M2_GATE)

RPD2 (100kΩ undefined)
- pin1(anode, pos, left): NETS(M2_GATE)
- pin2(cathode, neg, right): NETS(GND)

CM2 (100nF undefined)
- pin1(anode, pos, left): NETS(VBAT)
- pin2(cathode, neg, right): NETS(M2_NEG)

M2_POS
- pin1: NETS(VBAT)

M2_NEG
- pin1: NETS(M2_NEG)

Q3 (AO3400A)
- pin1(G): NETS(M3_GATE)
- pin2(S): NETS(GND)
- pin3(D): NETS(M3_NEG)

D3 (SS34)
- pin1(cathode, neg): NETS(VBAT)
- pin2(anode, pos): NETS(M3_NEG)

RG3 (100Ω undefined)
- pin1(anode, pos, left): NETS(M3_PWM)
- pin2(cathode, neg, right): NETS(M3_GATE)

RPD3 (100kΩ undefined)
- pin1(anode, pos, left): NETS(M3_GATE)
- pin2(cathode, neg, right): NETS(GND)

CM3 (100nF undefined)
- pin1(anode, pos, left): NETS(VBAT)
- pin2(cathode, neg, right): NETS(M3_NEG)

M3_POS
- pin1: NETS(VBAT)

M3_NEG
- pin1: NETS(M3_NEG)

Q4 (AO3400A)
- pin1(G): NETS(M4_GATE)
- pin2(S): NETS(GND)
- pin3(D): NETS(M4_NEG)

D4 (SS34)
- pin1(cathode, neg): NETS(VBAT)
- pin2(anode, pos): NETS(M4_NEG)

RG4 (100Ω undefined)
- pin1(anode, pos, left): NETS(M4_PWM)
- pin2(cathode, neg, right): NETS(M4_GATE)

RPD4 (100kΩ undefined)
- pin1(anode, pos, left): NETS(M4_GATE)
- pin2(cathode, neg, right): NETS(GND)

CM4 (100nF undefined)
- pin1(anode, pos, left): NETS(VBAT)
- pin2(cathode, neg, right): NETS(M4_NEG)

M4_POS
- pin1: NETS(VBAT)

M4_NEG
- pin1: NETS(M4_NEG)

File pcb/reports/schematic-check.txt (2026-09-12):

Detected entrypoint: 'index.circuit.tsx'
Each child in a list should have a unique "key" prop.

Check the render method of `board`. It was passed a child from Drone. See https://react.dev/link/warning-keys for more information.
trace: `key` is not a prop. Trying to access it will result in `undefined` being returned. If you need to access the same value within the child component, you should pass it as a different prop. (https://react.dev/link/special-props)
<SchematicBoxPositions>
<SchematicBoxPlacement componentName="U1" positionAnchor="center" schX="0" schY="16" width="1.2" height="6.2" />
<SchematicBoxPlacement componentName="COUT1" positionAnchor="center" schX="35" schY="8" width="0.9" height="0.6" />
<SchematicBoxPlacement componentName="COUT2" positionAnchor="center" schX="38" schY="8" width="0.9" height="0.6" />
<SchematicBoxPlacement componentName="CESP" positionAnchor="center" schX="0" schY="8" width="0.9" height="0.6" />
<SchematicBoxPlacement componentName="CESPHF" positionAnchor="center" schX="3" schY="8" width="0.9" height="0.6" />
<SchematicBoxPlacement componentName="CIMU" positionAnchor="center" schX="32" schY="-12" width="0.9" height="0.6" />
<SchematicBoxPlacement componentName="CIMUB" positionAnchor="center" schX="35" schY="-12" width="0.9" height="0.6" />
<SchematicBoxPlacement componentName="CIO" positionAnchor="center" schX="38" schY="-12" width="0.9" height="0.6" />
<SchematicBoxPlacement componentName="REN" positionAnchor="center" schX="0" schY="5" width="0.9" height="0.6" />
</SchematicBoxPositions>
<SchematicPlacementIssues>
<TraceCanBeSimplifiedByMovingComponent schematicTraceId="schematic_trace_59" targetComponentName="REN" deltaSchX="-2.181" deltaSchY="0" newSchX="-2.181" newSchY="5" currentTurnCount="3" suggestedTurnCount="1" message="move REN left by 2.181 (to schX=-2.181, schY=5) to reduce this trace from 3 turns to 1" />
<DecouplingCapacitorsNotCloseTogether rail="V3V3" ground="GND" capacitorNames="COUT1, COUT2, CESP, CESPHF, CIMU, CIMUB, CIO" maxBodyGap="41.866" maxRecommendedBodyGap="4" message="Group the decoupling capacitors between V3V3 and GND closer together in this schematic block. Preserve their net connections." />
</SchematicPlacementIssues>

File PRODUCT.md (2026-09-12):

# Product
<!-- impeccable:product-schema 1 -->
## Platform
web
## Stack
Delegated by user: Three.js, TypeScript and Vite. Build directly in code.
## Users
The drone builder inspecting a compact PCB and its mechanical assembly before routing.
## Product Purpose
Inspect the actual placement together with motor, propeller, battery and attachment envelopes.
## Capabilities and Constraints
Orbit, exploded view, visibility toggles and component inspection. Separate pcb/ and cad/ folders. Vercel hosting. PCB is two layers, top-side assembly, 80 mm motor diagonal and 46 mm props. Routing excluded. Mechanical envelopes are provisional.
## Evidence on Hand
Two supplied design specifications; empty initial repository. No measured thrust, mass or mechanical-fit data.

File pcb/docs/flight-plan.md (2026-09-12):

**Yes—an ESP-based microdrone can fly smoothly. For your single-PCB build, I would choose an ESP32-S3, a supported SPI IMU, four 716 brushed motors, and 46 mm propellers.** The image above is Espressif’s reference-drone style, not a render of your proposed PCB. Espressif’s own hardware reference uses the same **716-motor + 46 mm-propeller class**, so this is a sensible starting point rather than an arbitrary combination. ([Espressif Systems][1])

The important distinction: **good components make smooth flight possible; matched propulsion, clean power, firmware timing, and tuning make it happen.** I would not promise “zero lag” or perfect hovering from a component list alone.

I’ve put the component selections, sourcing links, supporting circuitry, and mechanical checks into a workbook:

**[Download the drone component plan and BOM workbook](sandbox:/mnt/data/Tiny_ESP_Drone_Component_Plan.xlsx)**

## 1. My selected main electronics

For this version, I would move away from the earlier ESP-12F approach and use:

> **ESP32-S3-MINI-1-N8 + ICM-20602 over SPI + four AO3400A motor switches + TPS63031 3.3 V power supply.**

### JLCPCB sourcing

These are the **stock figures reported by JLCPCB’s public listings/search snapshots checked on 12 September 2026**. They are not reserved quantities or a checkout confirmation; JLC’s dynamically loaded inventory was not consistently exposed when opening the pages.

| Function | Exact component |  JLCPCB code | Quantity | Reported stock | Listed unit price |
| --- | --- | ---: | ---: | ---: | ---: |
| **ESP controller** | **ESP32-S3-MINI-1-N8** | **C2913206** | 1 | 4,997 | US$4.6743 |
| **IMU** | **TDK InvenSense ICM-20602** | **C97633** | 1 | 5,436 | US$6.2652 |
| **3.3 V buck-boost regulator** | **TPS63031DSKR** | **C15516** | 1 | 6,592 | US$1.1645 |
| **Motor switching MOSFET** | **Alpha & Omega AO3400A** | **C20917** | 4 | 987,885 | US$0.0847 each |
| **Motor flyback diode** | **MDD SS34** | **C8678** | 4 | 5,123,772 | US$0.0349 each |

Sources, in table order: ESP module, IMU, regulator, MOSFET, and diode. ([JLCPCB][2])

That is approximately **US$12.58 for these core electronic components**, before supporting passives, PCB fabrication, assembly, shipping, and taxes.

**Assembly warning:** the selected ESP module and ICM-20602 are listed as **Standard PCBA only**. Do not budget this as a basic “US$2 PCB” order; get a complete assembly quote before committing. ([JLCPCB][3])

### Why these particular parts?

**ESP32-S3 rather than ESP8266/ESP-12F:** ESP-FC recommends ESP32/ESP32-S3, while its ESP8266 support is no longer actively developed. For a new performance-focused board, I would start on the supported platform. The MINI module also lets you avoid designing the bare chip’s flash, crystal, and RF circuitry yourself. ([GitHub][4])

**ICM-20602 rather than QMI8658A:** I know you previously preferred QMI8658A. For this build, firmware compatibility matters more than saving a few dollars: ESP-FC explicitly lists **ICM20602**, while QMI8658 is not in its supported-IMU list. ICM42688 is also supported, but I could not reliably confirm its JLC stock, so it is not my final selection. ([GitHub][4])

**AO3400A:** its on-resistance is specified at a **2.5 V gate drive**, making it a reasonable candidate for switching these motors from 3.3 V GPIO. Still, its headline current rating is not a guarantee that a tiny PCB footprint will stay cool—test it with your actual propeller load. ([Alpha & Omega Semiconductor][5])

---

## 2. Motors, propellers, and battery to buy

### My propulsion selection

| Part | Selected specification | Quantity for one drone | Store and observed availability |
| --- | --- | ---: | --- |
| **Motors** | **716 brushed coreless, 3.7 V, 7 × 16 mm body, 0.8 mm shaft; two CW and two CCW** | 4 motors | **iFuture:** ₹120 listing, marked in stock |
| **Propellers** | **46 mm, 0.8 mm mounting hole, CW/CCW pair** | 2 pairs | **RC Market City:** ₹40 per pair, marked in stock; code **RMC-700075** |
| **Battery** | **YY702030, 1S 400 mAh, seller-rated 30C, ordinary 4.2 V LiPo** | 1 | **Quartz Components:** ₹237; **67 listed in stock** |

Motor specifications and listing: iFuture. Propeller dimensions, pairing, and availability: RC Market City. Battery specifications and availability: Quartz Components. ([iFuture Technology][6])

**One procurement issue needs resolving:** iFuture’s page says “CW+CCW pair” near the purchase button, but its detailed package section says one motor. **Ask them to confirm that your order contains two CW and two CCW motors before paying.** I would also buy a spare set and compare the motors rather than assume every generic 716 performs identically. ([iFuture Technology][6])

### Why I selected separate 46 mm props

The listed motor shaft is **0.8 mm**, and these props explicitly specify a **0.8 mm hole**. Their diameter is also the default size in Espressif’s 716-motor reference. This is a better-defined starting point than using whatever unlabelled propellers happen to arrive with the motors. **Do not enlarge or drill the propeller holes to make a mismatched set fit.** ([iFuture Technology][6])

### Battery details that matter

The selected battery is **7 × 20 × 30 mm**, with an **M.X2.0 female connector** and **4.2 V maximum charging voltage**. Do not assume its connector is interchangeable with PH2.0 or BT2.0; confirm the mating connector and polarity before designing that connection. ([QuartzComponents][7])

Espressif’s reference specifies 300 mAh, with 350 mAh as an option. The **400 mAh pack is my currently sourced option**, not a claim that a larger battery automatically improves flight. Weigh it and include it in the thrust test before freezing the PCB shape. ([Espressif Systems][1])

**The unresolved performance variable is the generic motor batch:** the seller does not provide a verified thrust curve for this exact motor–propeller combination. I would approve it for flight only after measuring thrust and current.

---

## 3. The supporting circuit your PCB needs

The five main electronic parts are **not** the whole circuit.

### Power architecture

```text
1S LiPo battery
    │
    ├── Battery rail ── four motors
    │                       │
    │                  four MOSFET switches
    │
    └── TPS63031 ── regulated 3.3 V
                         ├── ESP32-S3
                         └── ICM-20602
```

**The motors must not run through the 3.3 V regulator.** The TPS63031 supplies the controller and sensors. TI specifies up to **500 mA output in boost operation with input above 2.4 V**, and up to **800 mA in buck operation under its stated conditions**—not an unconditional 1 A output. Check the 3.3 V rail with the radio active and the motors starting. ([Texas Instruments][8])

### Required supporting parts

| Circuit area | What to include | Component reference / status |
| --- | --- | --- |
| **MOSFET gates** | Four **100 Ω series resistors** | **C22775**, 0603; catalog entry verified |
| **Motors off during reset** | Four **100 kΩ gate-to-ground resistors** | **C25803**, 0603; catalog entry verified |
| **Battery measurement** | Two **100 kΩ resistors** and an ADC filter capacitor | Same **C25803**; divider produces 2.1 V from a 4.2 V battery |
| **Boot/reset/chip-select pulls**  | Appropriate **10 kΩ resistors** | **C25804**, 0603; finalize count after schematic |
| **Reset timing** | Appropriate EN timing capacitor | **C15849**, 1 µF candidate |
| **Regulator capacitors** | TI reference starts with **10 µF input, 2 × 10 µF output, and 100 nF at VINA**  | Check effective capacitance after DC-bias derating |
| **Regulator inductor** | **1.5 µH shielded power inductor**, low resistance, adequate saturation current | **Final stocked MPN still needs selection** |
| **IMU/module bypassing** | Capacitors at the required supply/reference pins | Follow the exact manufacturer reference circuits |
| **Motor-noise suppression** | Provision for small ceramic capacitors at the motor terminals | Fit and evaluate during noise testing |
| **Battery-rail bulk capacitance** | Provision for a low-ESR capacitor near the power entry | Final value/package after transient and mass checks |
| **Programming** | GND, 3V3, TX, RX, EN and BOOT test pads | External programmer; no onboard USB-UART needed |

The resistor/capacitor candidate identities come from JLC’s catalog; the regulator’s reference values come from TI. **I could not independently verify current inventory for every supporting passive**, so those are explicitly marked separately in the workbook rather than presented as an order-ready manufacturing BOM. ([JLCPCB][9])

For each motor, the flyback diode goes **across the motor**: cathode to battery positive, anode to the MOSFET drain/motor-negative connection. The MOSFET is the low-side switch. Have this power stage and its thermal/current capacity reviewed before ordering.

I would omit **onboard charging, a camera, GPS, displays, and big connectors** from version one. First make the light, clean flight-control board work.

---

## 4. PCB and 3D-printed mechanical design

These are **my proposed design targets**, not measurements from a finished drone.

| Feature | Proposed target |
| --- | --- |
| Configuration | **Quad-X, single PCB** |
| PCB construction | **4 layers, around 1.0 mm thick**, subject to stiffness testing |
| Assembly | **All electronic components on the top side** |
| Opposite-motor centre distance | **80 mm diagonal** |
| Propellers | **46 mm** |
| All-up mass | **Aim for 30–35 g**, including battery and printed parts |
| Battery location | Under the centre, positioned to balance the completed drone |
| Printed parts | Keep the combined mass around **3–4 g or less** |

At an 80 mm motor diagonal, adjacent motor centres are approximately **56.6 mm apart**. With 46 mm props, that leaves about **10.6 mm between neighbouring propeller discs before adding guards**. The complete propeller footprint will be roughly **103 × 103 mm**, so this is palm-sized—not an 80 mm-wide finished aircraft.

### Placement priorities

Put the **IMU near the centre**, with short SPI traces, away from the switching regulator and large motor-current paths. Put the ESP antenna at an appropriate board edge and follow Espressif’s full antenna keepout; do not tuck it under the battery or copper-filled frame. Keep the converter’s switching loops compact and follow TI’s grounding/layout guidance. ([Espressif Documentation][10])

### The extra 3D parts I would design

| Printed part | Proposed construction |
| --- | --- |
| **Four motor collars** | Lightweight split collars for the measured 7 mm motor bodies. A restrained TPU insert is an option; avoid soft mounts that let motors tilt. |
| **Four propeller guards** | Thin PA12 nylon guards. Start with approximately **50–52 mm internal diameter**, then check clearance under maximum flex. |
| **Battery saddle** | Underside holder for the measured pack, with rounded surfaces and retention that does not squeeze or puncture the pouch. |
| **Small canopy and landing nubs** | Minimal cover over the electronics, with antenna clearance and access to programming pads. |

Print a **motor-fit test piece first**, not the entire frame. A tight collar can damage the motor body; a loose one can change thrust direction.

**Buy moulded flight propellers. I would not use home-printed propellers on this build.**

---

## 5. How to make it responsive instead of “buffering”

### Use existing flight firmware as the starting point

I would start with **ESP-FC**, which lists ESP32-S3, ICM20602, brushed-motor outputs, ESP-NOW reception, and angle mode. It is compatible with Betaflight Configurator, but **it is not simply Betaflight firmware for an ESP board**. You still need the correct build, pin mapping, sensor orientation, motor ordering, and tuning. ([GitHub][4])

### Keep the stabilization loop onboard

Your transmitter should send **what you want the drone to do**. The onboard controller should continuously decide how to adjust the motors.

```text
Handheld transmitter → desired throttle / roll / pitch / yaw

Onboard:
IMU → attitude/rate estimate → controller → four motor outputs
```

My initial implementation targets would be a **500 Hz–1 kHz stabilization loop**, with a supported high-frequency brushed PWM setting, then measurements of timing, motor heating, and vibration before increasing rates. These are starting targets—not settings I have validated on this proposed PCB.

For control, I would use **a dedicated ESP-NOW transmitter**, not a browser page sending an accumulating queue of commands. ESP-FC documents an ESP-NOW receiver and a transmitter-module project; a custom two-gimbal handset still requires compatible transmitter firmware. Its ordinary Wi-Fi configuration mode is separate and does not allow arming while active. ([GitHub][11])

The implementation should always use the **newest valid command**, reject stale data, and have a tested loss-of-link failsafe. More filtering is not automatically better; tune filtering and controller gains against measured vibration rather than hiding a badly balanced motor with excessive smoothing.

### “Stable” does not automatically mean stationary hovering

A six-axis IMU helps control attitude. It does **not**, by itself, provide reliable position hold or automatic height hold. Espressif’s additional flight modes use additional sensing; optical flow and distance sensing would be a separate second-stage project. ([Espressif Systems][12])

For version one, I would target **predictable self-levelling flight with responsive manual control**.

---

## Before ordering the flight PCB

The most useful next test is **one selected motor + one selected propeller + the selected battery**, measuring thrust and current at representative battery voltages. Aim for roughly **2:1 combined maximum static thrust to actual all-up weight** as a design target, rather than a drone that barely lifts off.

Then verify the 3.3 V rail under radio and motor load. Before any free flight, test motor order, rotation, IMU axes, arming, and link-loss behaviour **with the propellers removed**. An external **4.2 V 1S LiPo charger with suitable adjustable current** is also needed; its exact model remains unselected until the battery’s permitted charge current and connector are confirmed.

**My recommendation is this S3 + SPI ICM-20602 + 716/46 mm platform. The main electronics are selected, but I would not call the complete build “ready to manufacture” until the motor-pack ambiguity, regulator inductor, remaining passive stock, schematic review, and thrust test are resolved.**

The [workbook](sandbox:/mnt/data/Tiny_ESP_Drone_Component_Plan.xlsx) separates those unresolved items from the selected parts across four sheets: **core JLC BOM, PCB support, motors/accessories, and build/3D checks**.

[1]: https://docs.espressif.com/projects/espressif-esp-drone/en/latest/hardware.html "Hardware Reference — ESP-Drone documentation"
[2]: https://jlcpcb.com/partdetail/EspressifSystems-ESP32_S3_MINI_1N8/C2913206?utm_source=chatgpt.com "ESP32-S3-MINI-1-N8 | Espressif Systems - JLCPCB"
[3]: https://jlcpcb.com/partdetail/EspressifSystems-ESP32_S3_MINI_1N8/C2913206 "ESP32-S3-MINI-1-N8 | Espressif Systems | JLCPCB"
[4]: https://github.com/rtlopez/esp-fc "GitHub - rtlopez/esp-fc: Flight controller software for hobbyist - build your own flight controller. · GitHub"
[5]: https://www.aosmd.com/sites/default/files/res/datasheets/AO3400A.pdf "https://www.aosmd.com/sites/default/files/res/datasheets/AO3400A.pdf"
[6]: https://ifuturetech.org/product/716-3-7v-micro-coreless-motor/ "https://ifuturetech.org/product/716-3-7v-micro-coreless-motor/"
[7]: https://quartzcomponents.com/products/3-7v-30c-400mah-lithium-polymer-lipo-battery-yy702030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 "https://quartzcomponents.com/products/3-7v-30c-400mah-lithium-polymer-lipo-battery-yy702030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"
[8]: https://www.ti.com/lit/ds/symlink/tps63030.pdf "https://www.ti.com/lit/ds/symlink/tps63030.pdf"
[9]: https://jlcpcb.com/partdetail/0603WAF1000T5E/C22775 "https://jlcpcb.com/partdetail/0603WAF1000T5E/C22775"
[10]: https://documentation.espressif.com/esp32-s3-mini-1_mini-1u_datasheet_en.html "https://documentation.espressif.com/esp32-s3-mini-1_mini-1u_datasheet_en.html"
[11]: https://github.com/rtlopez/esp-fc/blob/master/docs/wireless.md "https://github.com/rtlopez/esp-fc/blob/master/docs/wireless.md"
[12]: https://docs.espressif.com/projects/espressif-esp-drone/en/latest/gettingstarted.html?utm_source=chatgpt.com "Get Started — ESP-Drone documentation - Espressif Systems"

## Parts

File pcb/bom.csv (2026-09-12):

References | Qty | JLCPCB | Manufacturer part | Type | Status
U1 | 1 | C2913206 | ESP32-S3-MINI-1-N8 | simple_chip | Candidate; verify inventory and ratings
U2 | 1 | C97633 | ICM-20602 | simple_chip | Candidate; verify inventory and ratings
U3 | 1 | C15516 | TPS63031DSKR | simple_chip | Candidate; verify inventory and ratings
L1 | 1 | C2041714 | SRN3015-1R5Y | simple_inductor | Candidate; verify inventory and ratings
CIN COUT1 COUT2 | 3 | C15850 | CL21A106KAYNNNE | simple_capacitor | Candidate; verify inventory and ratings
CVINA CESPHF CIMU CREG CADC CM1 CM2 CM3 CM4 | 9 | C14663 | CC0603KRX7R9BB104 | simple_capacitor | Candidate; verify inventory and ratings
CBULK | 1 | C5440143 | CS3225X7R476K160NRL | simple_capacitor | Candidate; verify inventory and ratings
CESP | 1 | C45783 | CL21A226MAQNNNE | simple_capacitor | Candidate; verify inventory and ratings
CEN | 1 | C15849 | CL10A105KB8NNNC | simple_capacitor | Candidate; verify inventory and ratings
CIMUB | 1 | C23630 | CL10A225KO8NNNC | simple_capacitor | Candidate; verify inventory and ratings
CIO | 1 | C57112 | 0603B103K500NT | simple_capacitor | Candidate; verify inventory and ratings
REN RBOOT RCS | 3 | C25804 |  | simple_resistor | Candidate; verify inventory and ratings
RADCH RADCL RPD1 RPD2 RPD3 RPD4 | 6 | C25803 |  | simple_resistor | Candidate; verify inventory and ratings
Q1 Q2 Q3 Q4 | 4 | C20917 | AO3400A | simple_chip | Candidate; verify inventory and ratings
D1 D2 D3 D4 | 4 | C8678 | SS34 | simple_diode | Candidate; verify inventory and ratings
RG1 RG2 RG3 RG4 | 4 | C22775 |  | simple_resistor | Candidate; verify inventory and ratings

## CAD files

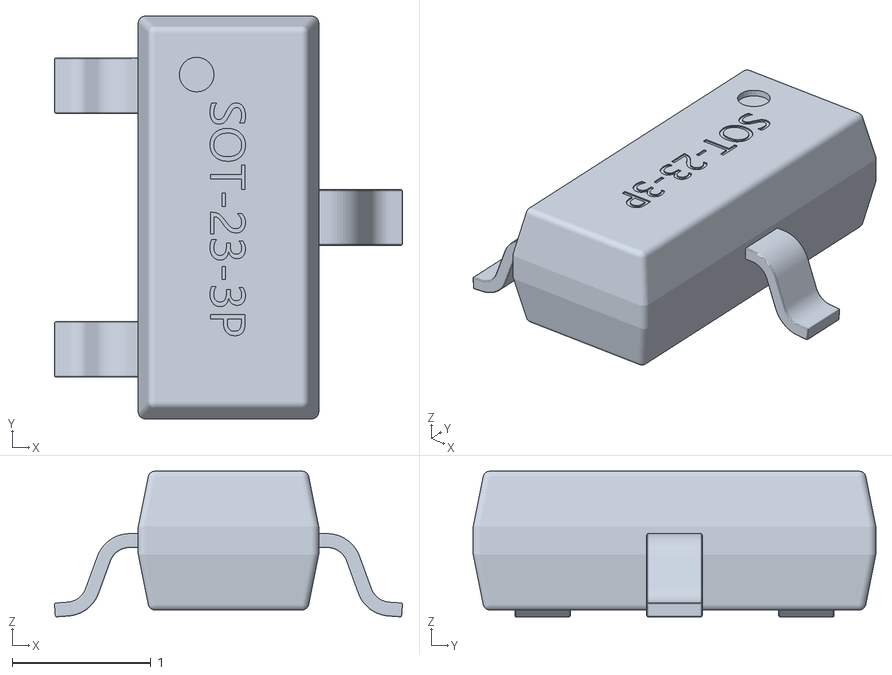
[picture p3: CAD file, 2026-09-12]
cad/public/pcb/imports/AO3400A/AO3400A.obj
2.51 x 2.90 x 1.05

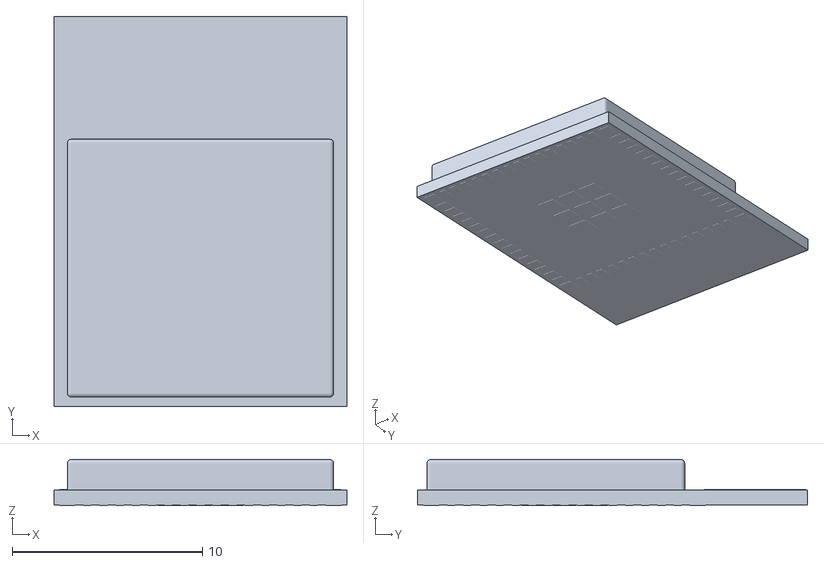
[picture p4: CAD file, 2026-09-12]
cad/public/pcb/imports/ESP32_S3_MINI_1_N8/ESP32_S3_MINI_1_N8.obj
15.4 x 20.5 x 2.42

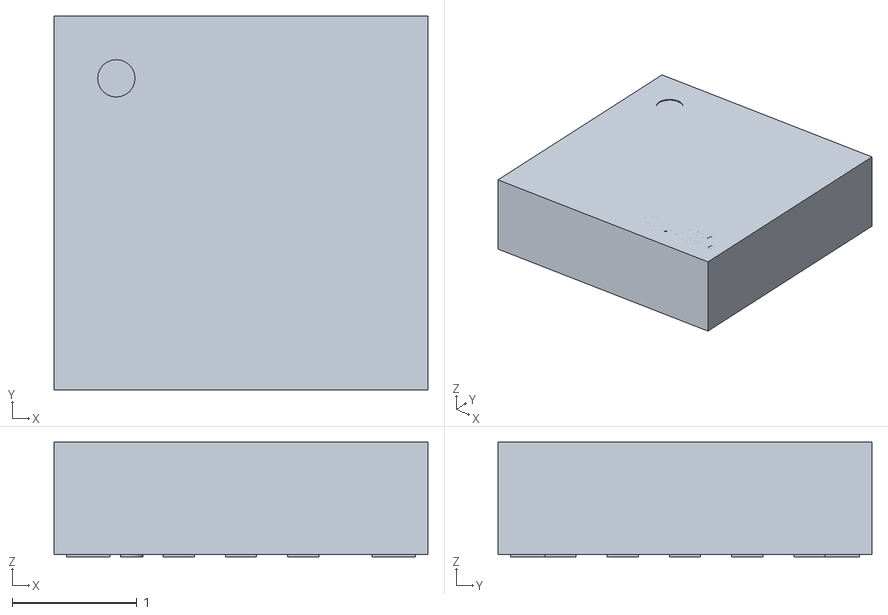
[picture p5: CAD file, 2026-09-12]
cad/public/pcb/imports/ICM_20602/ICM_20602.obj
3.00 x 3.00 x 0.921

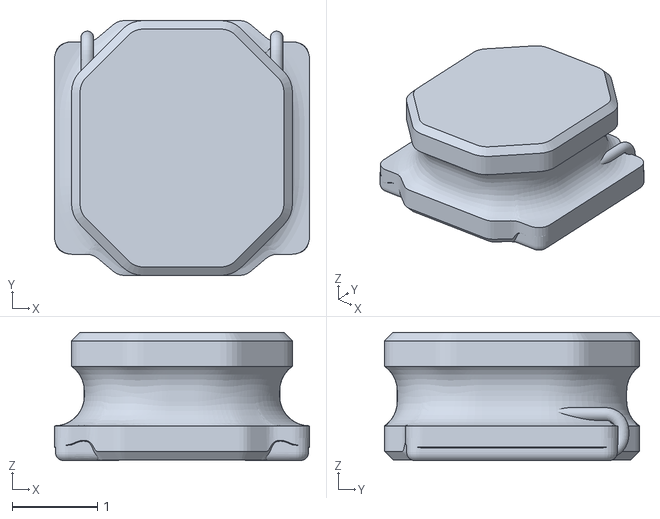
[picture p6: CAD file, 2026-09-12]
cad/public/pcb/imports/SRN3015_1R5Y/SRN3015_1R5Y.obj
3.00 x 3.00 x 1.51

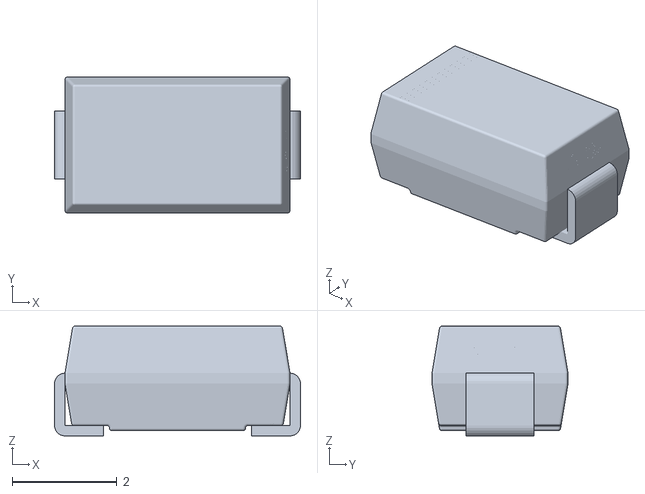
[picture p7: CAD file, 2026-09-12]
cad/public/pcb/imports/SS34/SS34.obj
4.70 x 2.60 x 2.10

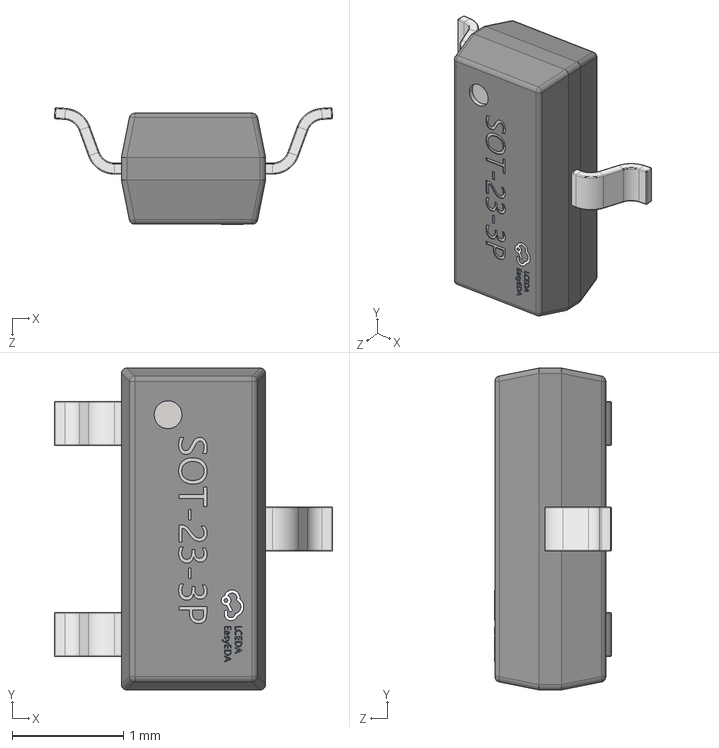
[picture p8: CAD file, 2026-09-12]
pcb/imports/AO3400A/AO3400A.step
2.51 x 2.90 x 1.05 mm

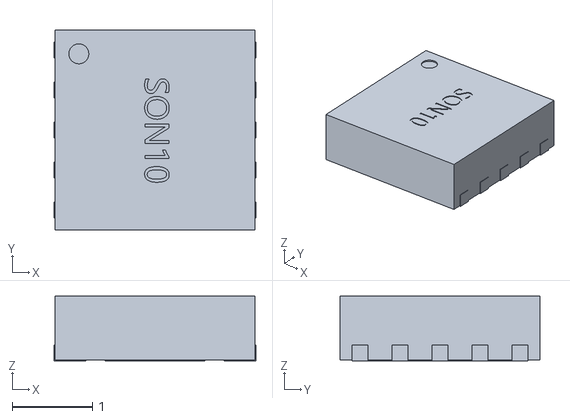
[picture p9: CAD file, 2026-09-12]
cad/public/pcb/imports/TPS63031DSKR/TPS63031DSKR.obj
2.52 x 2.50 x 0.81

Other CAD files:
pcb/imports/ESP32_S3_MINI_1_N8/ESP32_S3_MINI_1_N8.step
pcb/imports/ICM_20602/ICM_20602.step
pcb/imports/SRN3015_1R5Y/SRN3015_1R5Y.step
pcb/imports/SS34/SS34.step
pcb/imports/TPS63031DSKR/TPS63031DSKR.step

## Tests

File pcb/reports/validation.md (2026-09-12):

# Placement validation

Commands run with tscircuit 0.0.2527 and CLI 0.1.2063.

- Netlist: zero errors, zero warnings.
- PCB placement: zero errors, zero warnings; no DRC suppression is applied.
- Schematic placement: no overlapping component bodies or inner labels after the AO3400A symbol override. The tool still recommends gathering all 3.3 V decouplers across different functional sections into one cluster; this is intentionally not followed because each decoupler belongs beside its own device. Trace-simplification suggestions are advisory.
- Build: succeeds with routing disabled; outputs circuit JSON, PCB SVG/PNG and schematic SVG.
- Automated electrical assertions: regulator power domains, IMU reserved/reference pins, SPI connectivity, four motor-driver topologies, component count, layer, no error records, no routed copper, and motor diagonal.
- Routing difficulty: strongest reported local region was 8.8% estimated failure probability inside U1's pad field. This is a heuristic, not a routing guarantee. Power routing remains a manual task.
- IMU SCK straight-line connection: 7.40 mm.

The full build retains warnings for descriptive reference names, generic pin specifications, pad-only components without courtyards, supplier footprint differences, and schematic reference-label styling. These are not placement errors and are not silenced. Review them before fabrication. Keepout support is a confirmed tooling blocker recorded in ISSUES.md.

Battery retention revision: both placement checks pass; five tests / 146 assertions pass, including the rounded slot dimensions and component clearance across the top tie lane. Motor apertures remain provisional pending mount selection.

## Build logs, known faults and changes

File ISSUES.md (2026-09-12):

# Open issues

Placement prototype only. Routing is intentionally deferred; do not order these outputs.

- **Resolved deployment asset blocker:** the first production smoke test found `/pcb/circuit.json` and `/pcb/provenance.json` returned 404. The root `.vercelignore` pattern `pcb/` also excluded the viewer's `cad/public/pcb/` assets. The exclusion is now anchored to `/pcb/`. Redeployment restored the assets; both desktop and mobile browser tests pass against the public production URL.

- **Confirmed tscircuit blocker — keepouts:** `tsci check netlist` fails with `Unsupported component type "pcbkeepout"` in the installed core despite the element being documented. Keepout requirements are recorded in `pcb/keepouts.json` and displayed in CAD; they must be implemented as actual copper exclusions before routing. Placement builds omit the unsupported JSX rather than pretending the exclusions are enforced.
- **Imported AO3400A schematic symbol:** schematic placement reports colliding top/bottom inner labels on the imported 0.68 × 0.4-unit symbol. Resolved with an explicit readable pin-box symbol while preserving the JLCPCB footprint, model and verified G/S/D mapping.

- **Battery connector:** YY702030 specifies M.X2.0, whose mating part/polarity is unconfirmed. This revision uses marked solder pads and a separately verified pigtail.
- **Mechanical validation:** collar fit, retention, arm stiffness, guard flex, assembled antenna clearance, and battery insulation need physical checks. Motors, props and battery in CAD are dimensional envelopes, not certified vendor models. No flight or mass claim is validated.
- **Power qualification:** TPS63031 low-battery radio load, motor startup current, inductor saturation and capacitor DC-bias derating require verification before manufacture.
- **Manufacturing release:** pin mapping review, routed DRC, copper keepouts and actual JLCPCB stock/assembly quotation remain required.
- **Resolved tooling reference gap:** linked CLI/element files in the original local skill were absent. The CLI bootstrap installed working project-local references; installed help/types and manufacturer documents were also used.

- **Motor mount procurement:** a dimensioned rubber mount for the 7 mm motor and 1 mm PCB has not been selected. The 7.6 mm PCB apertures and collar geometry remain placeholders. Confirm bore, panel groove, flange retention and resistance to motor tilt before changing holes or buying mounts.
- **Zip-tie battery retention:** two 1.8 × 3.2 mm rounded slots accept the proposed 2.5 mm tie. Use a thin insulating pad and smooth slot edges; verify actual tie thickness/head and pack dimensions, longitudinal slip, and avoid compressing the pouch or bending the PCB. The 20 × 30 mm pack is centered at (0, -5), overhanging the rear center edge by 2 mm. Prototype fit remains required.
